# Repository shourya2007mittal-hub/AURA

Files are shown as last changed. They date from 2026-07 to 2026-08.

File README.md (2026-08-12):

# AURA


I made a custom Tailless twin motor RC Plane with custom Flight Controller (based on STM32). The Flight Controller  will have 2 IMU's and a barometer for precise data collection. The Plane design will include a tailless structure and the motions will be controlled by the flaps on the wings. I have also made custom ESc for the Plane as well.

## Features
- Base on  STM32F401CBUx 
- Has dual IMU (MPU_6050)(ICM-20948)
- Has a Barometer (BMP280)
- Uses 2 Light-Weight Servoes
- Uses Custom flight-controller
- Tailless twin motor Design
- Custom ESC for plane 

# ✈️ RC Plane Bill of Materials (BOM)

This repository contains the complete **Bill of Materials (BOM)** for the RC Plane project, including component quantities, unit prices, total costs, and supplier links.

## 📦 Bill of Materials

| Item | Quantity | Unit Price (USD) | Total Price (USD) | Source |
|---|:---:|---:|---:|---|
| PCB + PCBA (Flight Controller + ESC) | 1 | $253.46 | $253.46 | https://jlcpcb.com |
| PCB Shipping + coupons | 1 | $17.32 | $17.32 | https://jlcpcb.com |
| Brushless Motor | 2 | $15.20 | $30.40 | https://robu.in/product/r2207-2207-2450kv-ccw-fpv-brushless-motor/ |
| Receiver / Transmitter | 1 | $0 | $0 Funded by me |https://robocraze.com/products/fly-sky-fs-i6x-2-4ghz-6ch-afhds-2a-rc-transmitter-with-fs-ia10b-2-4ghz-10ch-receiver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 |
| 12V Battery | 1 | $5.78 | $5.78 | https://robocraze.com/products/11-1v-2200mah-li-ion-battery?_pos=18&_sid=25292ddd5&_ss=r |
| SG90 Servo | 2 | $0.96 | $1.92 | https://robocraze.com/products/sg90-micro-servo-motor?_pos=1&_sid=88e48e080&_ss=r |
| 3D Printed Plane | 1 | $41.86 | $41.86 |https://jlc3dp.com/ |

---

## 💰 Cost Summary

| Category | Amount (USD) |
|---|---:|
| Total Component Cost | **$352.74** |

---

## 📋 Components Included

- PCB + PCBA
- PCB Shipping
- Brushless Motors (×2)
- Electronic Speed Controllers (ESCs) (×2)
- Receiver / Transmitter
- 12V Battery
- SG90 Micro Servos (×2)
- 3D Printed Aircraft Frame

### Schematic Flight Controller


###  PCB Design Flight Controller




### Schematic ESC


###  PCB Design ESC




### 3D Design 






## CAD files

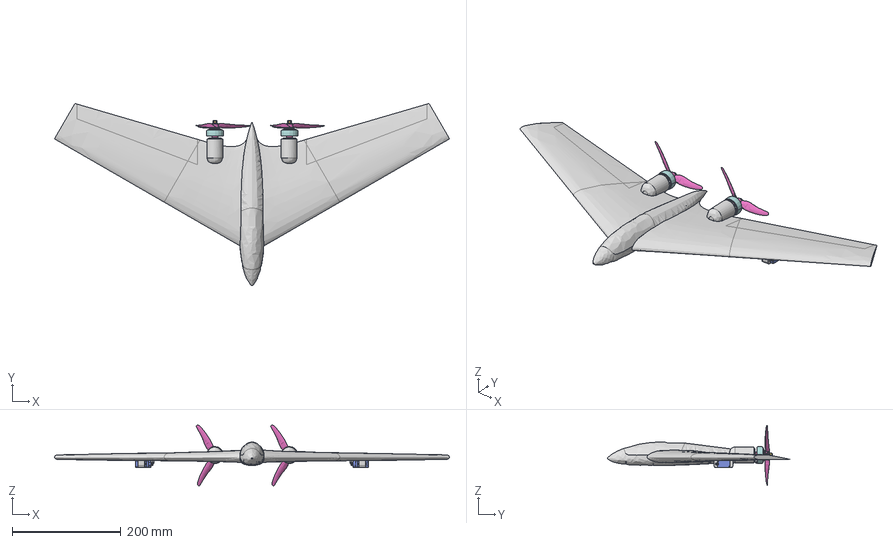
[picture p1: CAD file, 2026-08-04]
CAD/Aura.step
726.0 x 334.6 x 111.7 mm
D_SMA x 2
R_0603_1608Metric (1) x 62
C_0805_2012Metric x 10
PinHeader_1x01_P254mm_Vertical x 10
C_1206_3216Metric x 10
SOT-223 x 2
C_0603_1608Metric x 6
R_2512_6332Metric x 2
PinHeader_1x03_P254mm_Vertical x 2
PinHeader_1x04_P254mm_Vertical x 2
D_SOD_523 x 6
SOT-23-6 x 2
R_eA4A7_PCB x 2

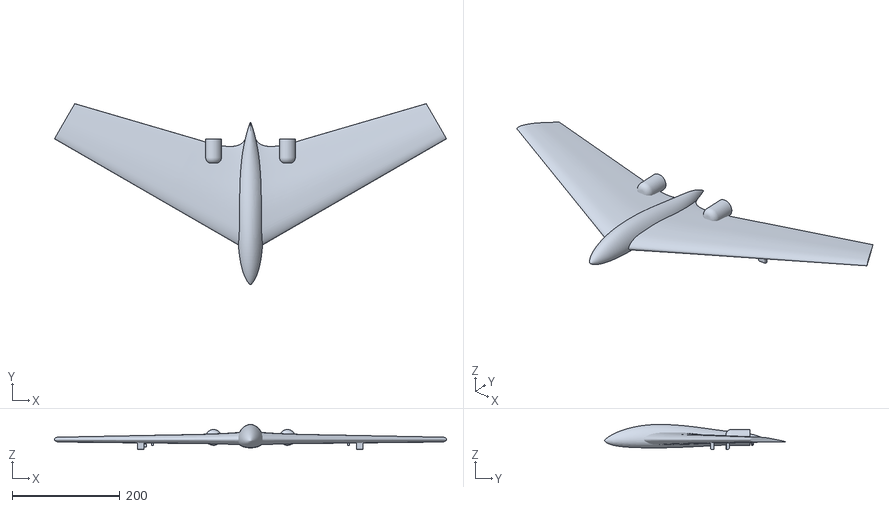
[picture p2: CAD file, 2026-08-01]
Production/CAD/AURA.stl
726.0 x 334.6 x 46.5

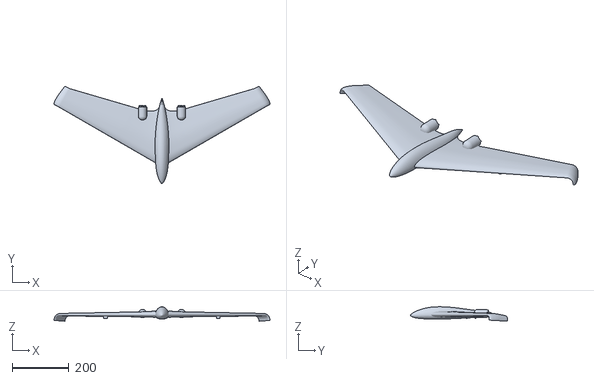
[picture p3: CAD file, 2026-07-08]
Production/CAD/AURA3D.stl
760.6 x 343.3 x 51.2

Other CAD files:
CAD/Aura.f3d

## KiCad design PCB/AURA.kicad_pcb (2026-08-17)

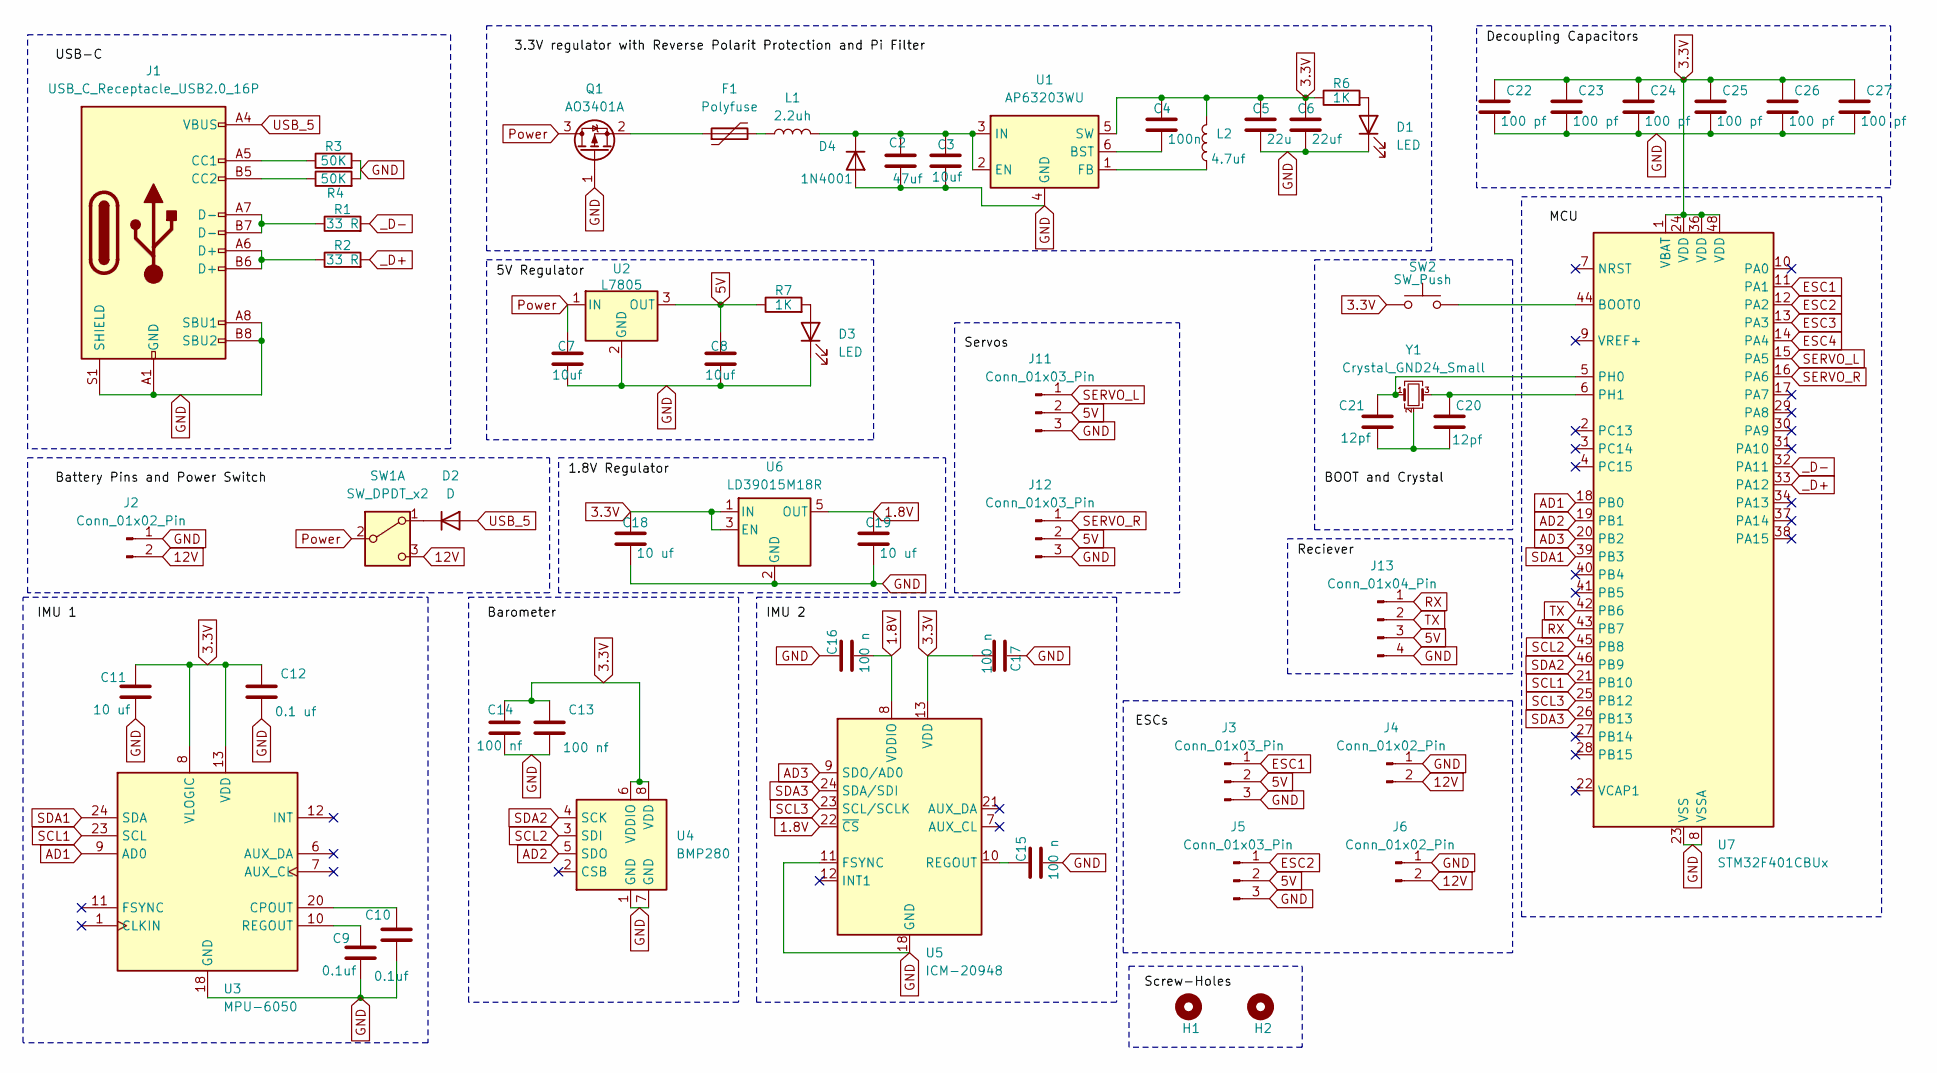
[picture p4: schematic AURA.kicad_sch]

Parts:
C2: 47uf; C_0201_0603Metric
C3, C7, C8: 10uf; C_0201_0603Metric
C4: 100n; C_0201_0603Metric
C5: 22u; C_0201_0603Metric
C6: 22uf; C_0201_0603Metric
C9, C10: 0.1uf; C_0201_0603Metric
C11, C18, C19: 10 uf; C_0201_0603Metric
C12: 0.1 uf; C_0201_0603Metric
C13, C14: 100 nf; C_0201_0603Metric
C15, C16, C17: 100 n; C_0201_0603Metric
C20, C21: 12pf; C_0201_0603Metric
C22, C23, C24, C25, C26, C27: 100 pf; C_0201_0603Metric
D1, D3: LED; LED_0201_0603Metric
D2: D; D_0201_0603Metric
D4: 1N4001; D_DO-41_SOD81_P5.08mm_Vertical_AnodeUp
F1: Polyfuse; C_0201_0603Metric
H1, H2: MountingHole; MountingHole_2.5mm_Pad
J1: USB_C_Receptacle_USB2.0_16P; USB_C_Receptacle_G-Switch_GT-USB-7010ASV
J2: Conn_01x02_Pin; AMASS_XT60-M_1x02_P7.20mm_Vertical
J3, J5, J11, J12: Conn_01x03_Pin; JST_EH_B3B-EH-A_1x03_P2.50mm_Vertical
J4, J6: Conn_01x02_Pin; AMASS_XT60-F_1x02_P7.20mm_Vertical
J13: Conn_01x04_Pin; JST_EH_B4B-EH-A_1x04_P2.50mm_Vertical
L1: 2.2uh; L_0603_1608Metric
L2: 4.7uf; L_0603_1608Metric
Q1: AO3401A; SOT-23
R1, R2: 33 R; R_0201_0603Metric_Pad0.64x0.40mm_HandSolder
R3, R4: 50K; R_0201_0603Metric_Pad0.64x0.40mm_HandSolder
R6, R7: 1K; R_0201_0603Metric_Pad0.64x0.40mm_HandSolder
SW1: SW_DPDT_x2; SW_PUSH_E-Switch_FS5700DP_DPDT
SW2: SW_Push; SW_Tactile_Straight_KSA0Axx1LFTR
U1: AP63203WU; TSOT-23-6
U2: L7805; TO-252-2
U3: MPU-6050; InvenSense_QFN-24_4x4mm_P0.5mm
U4: BMP280; Bosch_LGA-8_2x2.5mm_P0.65mm_ClockwisePinNumbering
U5: ICM-20948; InvenSense_QFN-24_3x3mm_P0.4mm
U6: LD39015M18R; SOT-23-5
U7: STM32F401CBUx; QFN-48-1EP_7x7mm_P0.5mm_EP5.6x5.6mm
Y1: Crystal_GND24_Small; Crystal_SMD_0603-4Pin_6.0x3.5mm

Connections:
1.8V: C16.2, C19.1, U5.8 (VDDIO), U5.22 (~CS), U6.5 (OUT)
3.3V: C4.1, C5.1, C6.1, C11.1, C12.1, C13.1, C14.1, C17.2, C18.1, C22.1, C23.1, C24.1, C25.1, C26.1, C27.1, L2.2, R6.1, SW2.1, U1.5 (SW), U3.8 (VLOGIC), U3.13 (VDD), U4.6 (VDDIO), U4.8 (VDD), U5.13 (VDD), U6.1 (IN), U6.3 (EN), U7.1 (VBAT), U7.24 (VDD), U7.36 (VDD), U7.48 (VDD)
5V: C8.1, J3.2, J5.2, J11.2, J12.2, J13.3, R7.1, U2.3 (OUT)
12V: J2.2, J4.2, J6.2, SW1.3 (C)
AD1: U3.9 (AD0), U7.18 (PB0)
AD2: U4.5 (SDO), U7.19 (PB1)
AD3: U5.9 (SDO/AD0), U7.20 (PB2)
ESC1: J3.1, U7.11 (PA1)
ESC2: J5.1, U7.12 (PA2)
ESC3: U7.13 (PA3)
ESC4: U7.14 (PA4)
GND: C2.2, C3.2, C5.2, C6.2, C7.2, C8.2, C9.2, C10.2, C11.2, C12.2, C13.2, C14.2, C15.2, C16.1, C17.1, C18.2, C19.2, C22.2, C23.2, C24.2, C25.2, C26.2, C27.2, D1.1 (K), D3.1 (K), D4.2 (A), J1.A1 (GND), J1.A8 (SBU1), J1.A12 (GND), J1.B1 (GND), J1.B8 (SBU2), J1.B12 (GND), J1.S1 (SHIELD), J2.1, J3.3, J4.1, J5.3, J6.1, J11.3, J12.3, J13.4, Q1.1 (G), R3.2, R4.2, U1.4 (GND), U2.2 (GND), U3.18 (GND), U4.1 (GND), U4.7 (GND), U5.11 (FSYNC), U5.18 (GND), U5.20 (GND), U6.2 (GND), U7.8 (VSSA), U7.23 (VSS), U7.35 (VSS), U7.47 (VSS), U7.49 (VSS)
unnamed: C20.2, C21.2, Y1.2 (G), Y1.4 (G)
unnamed: D1.2 (A), R6.2
unnamed: D2.1 (K), SW1.1 (A)
unnamed: D3.2 (A), R7.2
unnamed: C2.1, C3.1, D4.1 (K), L1.2, U1.2 (EN), U1.3 (IN)
unnamed: F1.2, L1.1
unnamed: J1.A5 (CC1), R3.1
unnamed: J1.B5 (CC2), R4.1
unnamed: J1.A6 (D+), J1.B6 (D+), R2.1
unnamed: J1.A7 (D-), J1.B7 (D-), R1.1
unnamed: F1.1, Q1.2 (S)
unnamed: C4.2, U1.6 (BST)
unnamed: L2.1, U1.1 (FB)
unnamed: C10.1, U3.20 (CPOUT)
unnamed: C9.1, U3.10 (REGOUT)
unnamed: C15.1, U5.10 (REGOUT)
unnamed: SW2.2, U7.44 (BOOT0)
unnamed: C21.1, U7.5 (PH0), Y1.1
unnamed: C20.1, U7.6 (PH1), Y1.3
Power: C7.1, Q1.3 (D), SW1.2 (B), U2.1 (IN)
RX: J13.1, U7.43 (PB7)
SCL1: U3.23 (SCL), U7.21 (PB10)
SCL2: U4.3 (SDI), U7.45 (PB8)
SCL3: U5.23 (SCL/SCLK), U7.25 (PB12)
SDA1: U3.24 (SDA), U7.39 (PB3)
SDA2: U4.4 (SCK), U7.46 (PB9)
SDA3: U5.24 (SDA/SDI), U7.26 (PB13)
SERVO_L: J11.1, U7.15 (PA5)
SERVO_R: J12.1, U7.16 (PA6)
TX: J13.2, U7.42 (PB6)
USB_5: D2.2 (A), J1.A4 (VBUS), J1.A9 (VBUS), J1.B4 (VBUS), J1.B9 (VBUS)
_D+: R2.2, U7.33 (PA12)
_D-: R1.2, U7.32 (PA11)

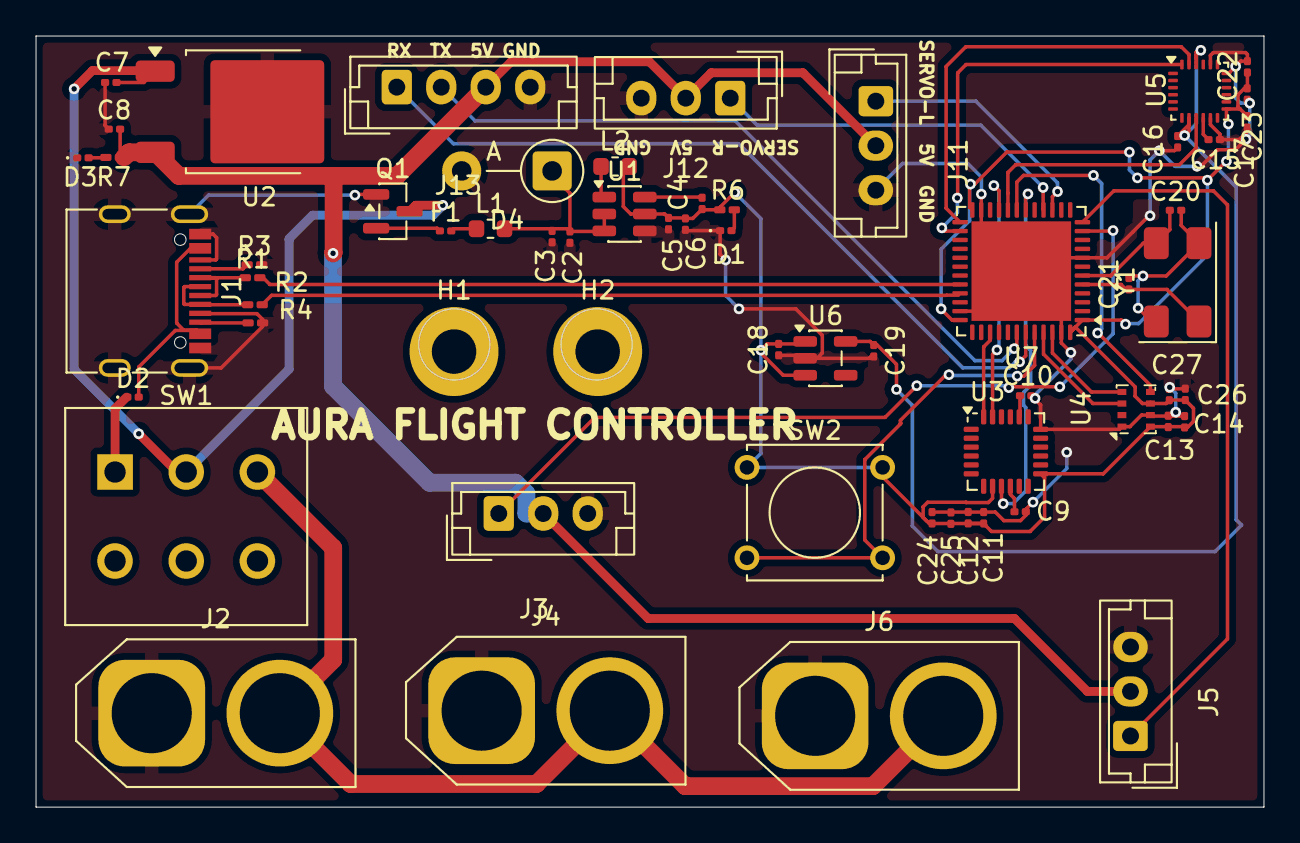
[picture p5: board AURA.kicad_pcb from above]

Board: 2 copper layers, 69.0 x 43.3 mm, 61 parts (0 on the bottom side), 43 nets.

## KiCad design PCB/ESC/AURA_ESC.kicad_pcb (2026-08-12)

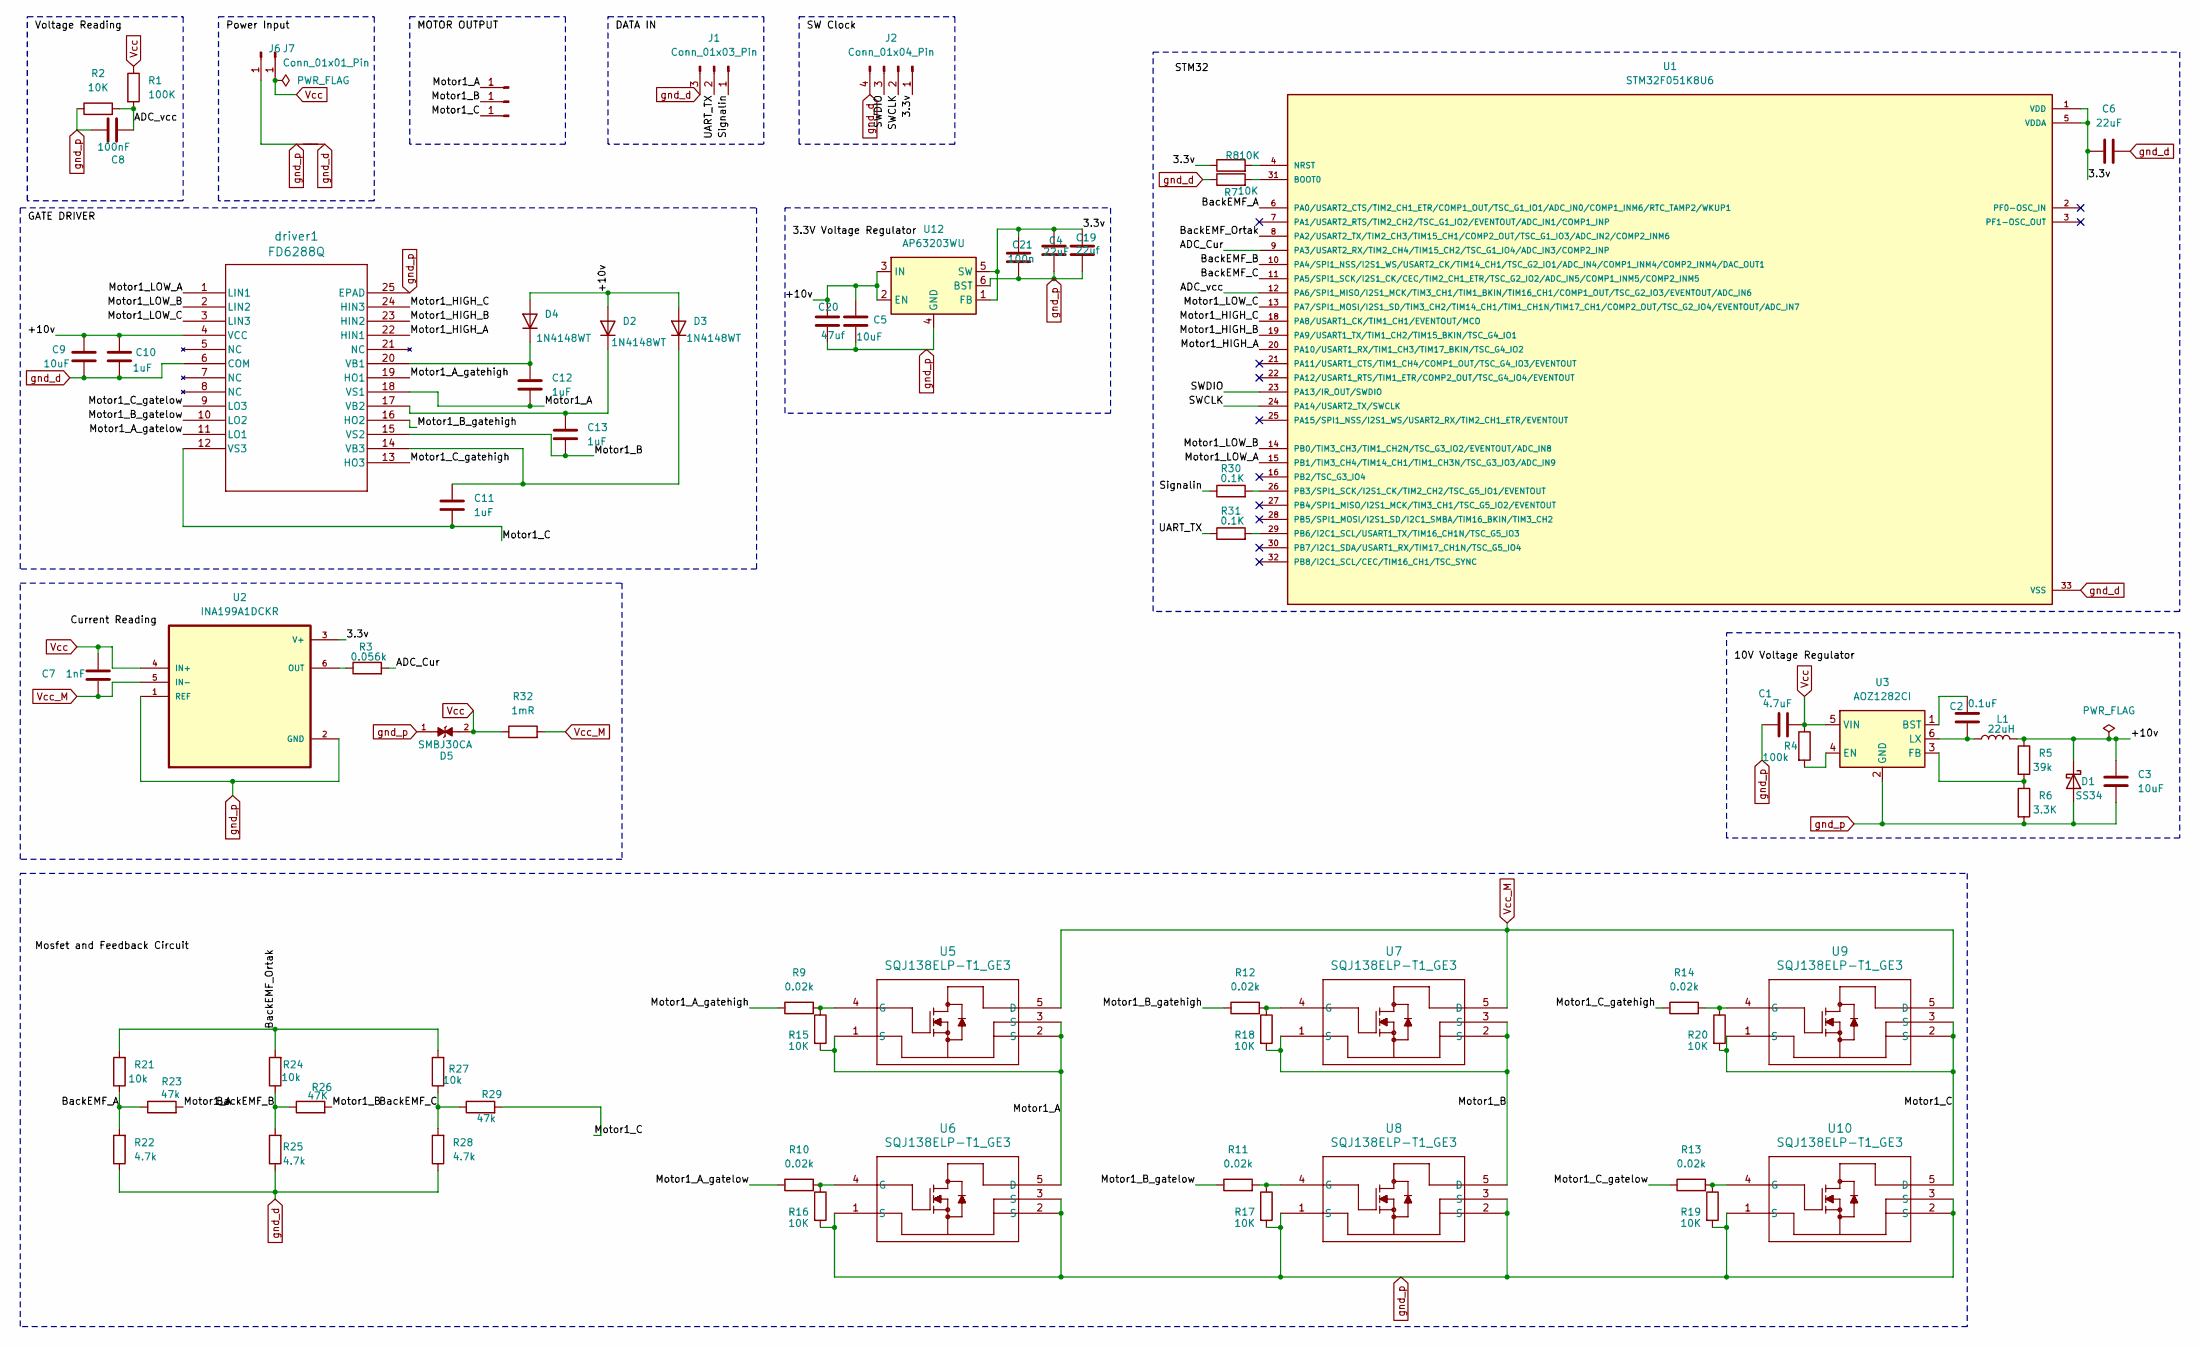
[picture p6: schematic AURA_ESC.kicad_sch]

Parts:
C1: 4.7uF; C_0805_2012Metric
C2: 0.1uF; C_0603_1608Metric
C3, C5, C9: 10uF; C_1206_3216Metric
C4, C6: 22uF; C_1206_3216Metric
C7: 1nF; C_0603_1608Metric
C8: 100nF; C_0603_1608Metric
C10, C11, C12, C13: 1uF; C_0805_2012Metric
C19: 22uf; C_0201_0603Metric
C20: 47uf; C_0201_0603Metric
C21: 100n; C_0201_0603Metric
D1: SS34; D_SMA
D2, D3, D4: 1N4148WT; D_SOD-523
D5: SMBJ30CA; DIOM4336X265N; PARTREV I2102
J1: Conn_01x03_Pin; PinHeader_1x03_P2.54mm_Vertical
J2: Conn_01x04_Pin; PinHeader_1x04_P2.54mm_Vertical
J3, J4, J5, J6, J7: Conn_01x01_Pin; PinHeader_1x01_P2.54mm_Vertical
L1: 22uH; L_6.3x6.3_H3
NT1: NetTie_2; NetTie-2_SMD_Pad0.5mm
R1: 100K; R_0603_1608Metric
R2, R7, R8, R15, R16, R17, R18, R19, R20: 10K; R_0603_1608Metric
R3: 0.056k; R_0603_1608Metric
R4: 100k; R_0603_1608Metric
R5: 39k; R_0603_1608Metric
R6: 3.3K; R_0603_1608Metric
R9, R10, R11, R12, R13, R14: 0.02k; R_0603_1608Metric
R21, R24, R27: 10k; R_0603_1608Metric
R22, R25, R28: 4.7k; R_0603_1608Metric
R23, R29: 47k; R_0603_1608Metric
R26: 47K; R_0603_1608Metric
R30, R31: 0.1K; R_0603_1608Metric
R32: 1mR; R_2512_6332Metric
U1: STM32F051K8U6; QFN50P500X500X60-33N; PARTREV 7
U2: INA199A1DCKR; SOT65P210X110-6N
U3: AOZ1282CI; SOT-23-6
U5, U6, U7, U8, U9, U10: SQJ138ELP-T1_GE3; PowerPAK_SO-8L_3_VIS
U12: AP63203WU; TSOT-23-6
driver1: FD6288Q; QFN24_FOR-M

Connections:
/+10v: C3.1, C5.1, C9.1, C10.1, C20.1, D1.1 (K), D2.2 (A), D3.2 (A), D4.2 (A), L1.2, R5.1, U12.2 (EN), U12.3 (IN), driver1.4 (VCC)
/ADC_Cur: R3.2, U1.9 (PA3/USART2_RX/TIM2_CH4/TIM15_CH2/TSC_G1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)
/ADC_vcc: C8.2, R1.2, R2.2, U1.12 (PA6/SPI1_MISO/I2S1_MCK/TIM3_CH1/TIM1_BK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)
/BackEMF_A: R21.1, R22.2, R23.1, U1.6 (PA0/USART2_CTS/TIM2_CH1_ETR/COMP1_OUT/T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)
/BackEMF_B: R24.1, R25.2, R26.1, U1.10 (PA4/SPI1_NSS/I2S1_WS/USART2_CK/TIM14_CH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)
/BackEMF_C: R27.1, R28.2, R29.1, U1.11 (PA5/SPI1_SCK/I2S1_CK/CEC/TIM2_CH1_ETR/T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)
/BackEMF_Ortak: R21.2, R24.2, R27.2, U1.8 (PA2/USART2_TX/TIM2_CH3/TIM15_CH1/COMP2_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)
/Motor1_A: C12.2, J3.1 (Pin_1_1), R15.2, R23.2, U5.1 (S), U5.2 (S), U5.3 (S), U6.5 (D), driver1.18 (VS1)
/Motor1_A_gatehigh: R9.1, driver1.19 (HO1)
/Motor1_A_gatelow: R10.1, driver1.11 (LO1)
/Motor1_B: C13.2, J4.1 (Pin_1_1), R18.2, R26.2, U7.1 (S), U7.2 (S), U7.3 (S), U8.5 (D), driver1.15 (VS2)
/Motor1_B_gatehigh: R12.1, driver1.16 (HO2)
/Motor1_B_gatelow: R11.1, driver1.10 (LO2)
/Motor1_C: C11.2, J5.1 (Pin_1_1), R20.2, R29.2, U9.1 (S), U9.2 (S), U9.3 (S), U10.5 (D), driver1.12 (VS3)
/Motor1_C_gatehigh: R14.1, driver1.13 (HO3)
/Motor1_C_gatelow: R13.1, driver1.9 (LO3)
/Motor1_HIGH_A: U1.20 (PA10/USART1_RX/TIM1_CH3/TIM17_BKIN/TSC_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), driver1.22 (HIN1)
/Motor1_HIGH_B: U1.19 (PA9/USART1_TX/TIM1_CH2/TIM15_BKIN/TSC_G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), driver1.23 (HIN2)
/Motor1_HIGH_C: U1.18 (PA8/USART1_CK/TIM1_CH1/EVENTOUT/MCO), driver1.24 (HIN3)
/Motor1_LOW_A: U1.15 (PB1/TIM3_CH4/TIM14_CH1/TIM1_CH3N/TSC_G3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), driver1.1 (LIN1)
/Motor1_LOW_B: U1.14 (PB0/TIM3_CH3/TIM1_CH2N/TSC_G3_IO2/EVENT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), driver1.2 (LIN2)
/Motor1_LOW_C: U1.13 (PA7/SPI1_MOSI/I2S1_SD/TIM3_CH2/TIM14_CH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), driver1.3 (LIN3)
/SWCLK: J2.2, U1.24 (PA14/USART2_TX/SWCLK)
/SWDIO: J2.3, U1.23 (PA13/IR_OUT/SWDIO)
/Signalin: J1.1, R30.1
/UART_TX: J1.2, R31.1
unnamed: C13.1, D2.1 (K), driver1.17 (VB2)
unnamed: C11.1, D3.1 (K), driver1.14 (VB3)
unnamed: C12.1, D4.1 (K), driver1.20 (VB1)
unnamed: R7.2, U1.31 (BOOT0)
unnamed: R8.2, U1.4 (NRST)
unnamed: R30.2, U1.26 (PB3/SPI1_SCK/I2S1_CK/TIM2_CH2/TSC_G5_IO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)
unnamed: R31.2, U1.29 (PB6/I2C1_SCL/USART1_TX/TIM16_CH1N/TSC_G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)
unnamed: R3.1, U2.6 (OUT)
unnamed: C2.1, U3.1 (BST)
unnamed: R4.2, U3.4 (EN)
unnamed: R5.2, R6.1, U3.3 (FB)
unnamed: C2.2, L1.1, U3.6 (LX)
unnamed: R9.2, R15.1, U5.4 (G)
unnamed: R10.2, R16.1, U6.4 (G)
unnamed: R12.2, R18.1, U7.4 (G)
unnamed: R11.2, R17.1, U8.4 (G)
unnamed: R14.2, R20.1, U9.4 (G)
unnamed: R13.2, R19.1, U10.4 (G)
VDD: C4.1, C6.2, C19.1, C21.1, J2.1, R8.1, U1.1 (VDD), U1.5 (VDDA), U1.17 (VDD), U2.3 (V+), U12.1 (FB), U12.5 (SW)
Vcc: C1.1, C7.2, D5.2, J7.1 (Pin_1_1), R1.1, R4.1, R32.1, U2.4 (IN+), U3.5 (VIN)
Vcc_M: C7.1, R32.2, U2.5 (IN-), U5.5 (D), U7.5 (D), U9.5 (D)
gnd_d: C6.1, C9.2, C10.2, J1.3, J2.4, NT1.2, R7.1, R22.1, R25.1, R28.1, U1.33 (VSS), driver1.6 (COM)
gnd_p: C1.2, C3.2, C4.2, C5.2, C8.1, C19.2, C20.2, C21.2, D1.2 (A), D5.1, J6.1 (Pin_1_1), NT1.1, R2.1, R6.2, R16.2, R17.2, R19.2, U2.1 (REF), U2.2 (GND), U3.2 (GND), U6.1 (S), U6.2 (S), U6.3 (S), U8.1 (S), U8.2 (S), U8.3 (S), U10.1 (S), U10.2 (S), U10.3 (S), U12.4 (GND), U12.6 (BST), driver1.25 (EPAD)

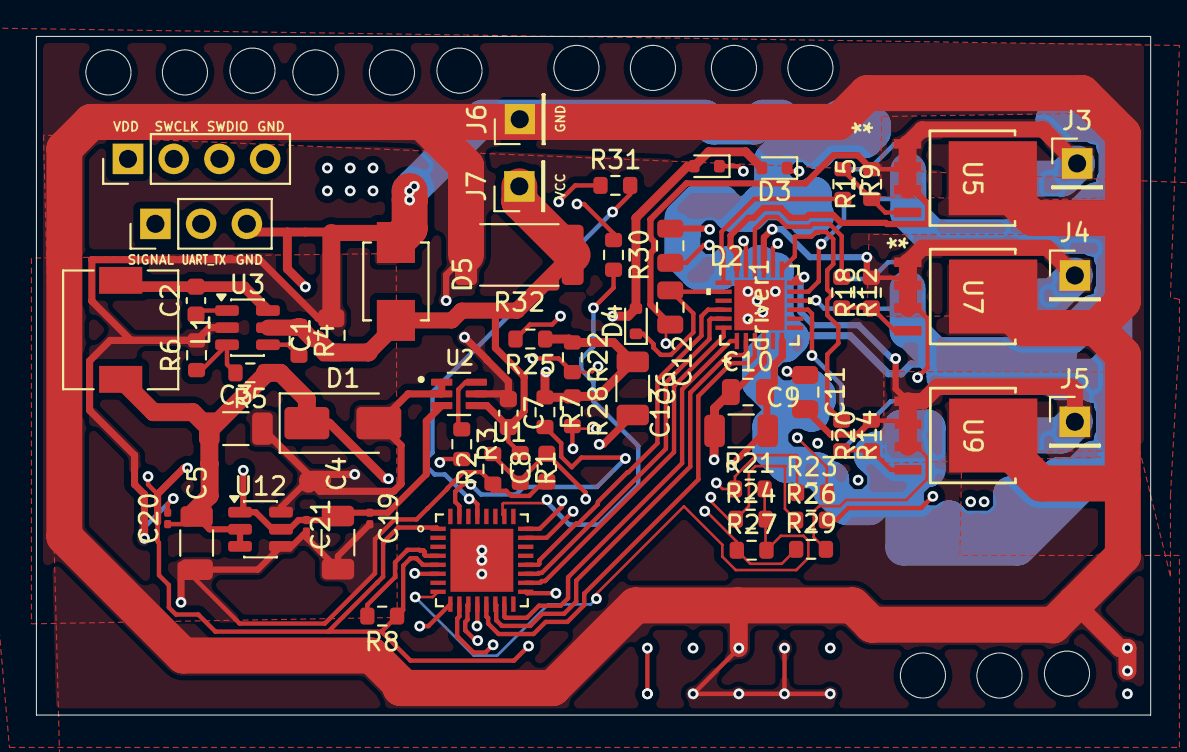
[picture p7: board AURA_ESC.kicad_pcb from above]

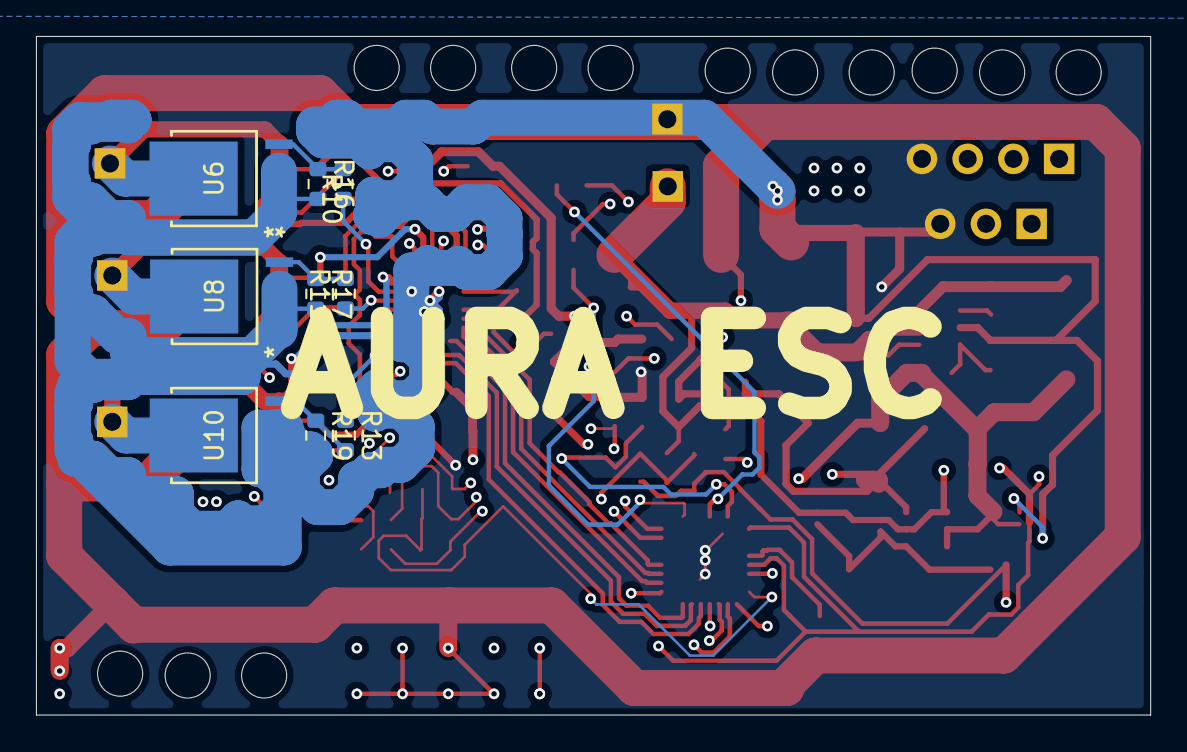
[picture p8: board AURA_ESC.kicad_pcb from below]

Board: 4 copper layers, 61.9 x 37.7 mm, 73 parts (9 on the bottom side), 49 nets.

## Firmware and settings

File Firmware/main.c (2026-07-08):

/*
 * ============================================================================
 * CUSTOM TAILLESS TWIN-MOTOR FLIGHT CONTROLLER FIRMWARE
 * Target MCU: STM32F401CBUx
 * ============================================================================
 */

#include "main.h"
#include <math.h>

// --- DEFINITIONS & CONSTANTS ---
#define MPU6050_ADDR    (0x68 << 1)
#define BMP280_ADDR     (0x76 << 1)
#define SBUS_FRAME_SIZE 25

// --- PERIPHERAL HANDLES ---
I2C_HandleTypeDef hi2c1;   // IMU 1 (MPU6050) via PB6/PB7
I2C_HandleTypeDef hi2c2;   // Barometer (BMP280) via PB10/PB3
TIM_HandleTypeDef htim1;   // ESCs (PA8, PA9)
TIM_HandleTypeDef htim2;   // Servos (PA0, PA1)
UART_HandleTypeDef huart1; // SBUS Receiver Input (PA10)

// --- FLIGHT CONTROL VARIABLES ---
float roll_input = 0.0f, pitch_input = 0.0f, throttle_input = 1000.0f;
float current_roll = 0.0f, current_pitch = 0.0f;
float gyro_bias_x = 0.0f, gyro_bias_y = 0.0f;

// PID Tuning Constants (Adjust these during test flights)
float Kp_roll = 1.2f,  Ki_roll = 0.05f,  Kd_roll = 0.1f;
float Kp_pitch = 1.5f, Ki_pitch = 0.05f, Kd_pitch = 0.1f;

// PID Memory Registers
float error_roll, integral_roll, derivative_roll, last_error_roll, out_roll;
float error_pitch, integral_pitch, derivative_pitch, last_error_pitch, out_pitch;

// SBUS Protocol Variables
uint8_t sbus_buffer[SBUS_FRAME_SIZE];
uint16_t sbus_channels[4];
uint8_t sbus_index = 0;
uint8_t is_armed = 0;
uint8_t rx_byte;

// Barometer Calibration Factors
uint16_t dig_T1; int16_t dig_T2, dig_T3; uint16_t dig_P1;
int16_t dig_P2, dig_P3, dig_P4, dig_P5, dig_P6, dig_P7, dig_P8, dig_P9;

// --- FUNCTION PROTOTYPES ---
void SystemClock_Config(void);
static void MX_GPIO_Init(void);
static void MX_I2C1_Init(void);
static void MX_I2C2_Init(void);
static void MX_TIM1_Init(void);
static void MX_TIM2_Init(void);
static void MX_USART1_UART_Init(void);

void IMU_Calibrate(void);
void IMU_Read(float *r, float *p);
void BMP280_Init(void);
float BMP280_GetAltitude(void);
void Mix_Elevons(float throttle, float roll, float pitch);

// --- MAIN PROGRAM EXECUTION ---
int main(void) {
    // Reset of all peripherals, Initializes the Flash interface and the Systick.
    HAL_Init();

    // Configure the system clock to 84 MHz using the 25MHz external crystal
    SystemClock_Config();

    // Initialize all configured peripherals
    MX_GPIO_Init();
    MX_I2C1_Init();
    MX_I2C2_Init();
    MX_TIM1_Init();
    MX_TIM2_Init();
    MX_USART1_UART_Init();

    // Device Sensors Boot & Calibration Sequence
    BMP280_Init();
    IMU_Calibrate();
    
    // Start Non-blocking UART Reception for RC Signal
    HAL_UART_Receive_IT(&huart1, &rx_byte, 1);

    // Start PWM Hardware Timers
    HAL_TIM_PWM_Start(&htim1, TIM_CHANNEL_1); // Left ESC
    HAL_TIM_PWM_Start(&htim1, TIM_CHANNEL_2); // Right ESC
    HAL_TIM_PWM_Start(&htim2, TIM_CHANNEL_1); // Left Servo
    HAL_TIM_PWM_Start(&htim2, TIM_CHANNEL_2); // Right Servo

    uint32_t loop_timer = HAL_GetTick();

    while (1) {
        // Main Flight Controller Loop (Executes strictly at 200Hz -> every 5ms)
        if ((HAL_GetTick() - loop_timer) >= 5) {
            loop_timer = HAL_GetTick();

            // 1. Refresh Flight Performance Matrix Data
            IMU_Read(&current_roll, &current_pitch);
            float current_altitude = BMP280_GetAltitude();

            // 2. Structural Safety Timeout Arm Interlock
            if (!is_armed) {
                __HAL_TIM_SET_COMPARE(&htim1, TIM_CHANNEL_1, 1000); // Force Motors Off
                __HAL_TIM_SET_COMPARE(&htim1, TIM_CHANNEL_2, 1000);
                continue; // Skip PID execution if safety switch is down
            }

            // 3. Roll Axis PID Controller
            error_roll = roll_input - current_roll;
            integral_roll += error_roll * 0.005f;
            derivative_roll = (error_roll - last_error_roll) / 0.005f;
            out_roll = (Kp_roll * error_roll) + (Ki_roll * integral_roll) + (Kd_roll * derivative_roll);
            last_error_roll = error_roll;

            // 4. Pitch Axis PID Controller
            error_pitch = pitch_input - current_pitch;
            integral_pitch += error_pitch * 0.005f;
            derivative_pitch = (error_pitch - last_error_pitch) / 0.005f;
            out_pitch = (Kp_pitch * error_pitch) + (Ki_pitch * integral_pitch) + (Kd_pitch * derivative_pitch);
            last_error_pitch = error_pitch;

            // 5. Send Mixed Commands to Control Surfaces and Power Units
            Mix_Elevons(throttle_input, out_roll, out_pitch);
        }
    }
}

// --- MIXING & CONTROL SURFACE LOGIC ---
void Mix_Elevons(float throttle, float roll, float pitch) {
    // Elevon Aerodynamic Mixer Logic for Tailless Aircraft
    float s_left  = 1500 + pitch + roll;
    float s_right = 1500 - pitch + roll;

    // Hard Clip Servo Output Constraints (1000us to 2000us)
    s_left  = (s_left > 2000) ? 2000 : ((s_left < 1000) ? 1000 : s_left);
    s_right = (s_right > 2000) ? 2000 : ((s_right < 1000) ? 1000 : s_right);

    __HAL_TIM_SET_COMPARE(&htim2, TIM_CHANNEL_1, (uint32_t)s_left);
    __HAL_TIM_SET_COMPARE(&htim2, TIM_CHANNEL_2, (uint32_t)s_right);

    // Twin Engine Differential Thrust Mixing to assist Yaw Control
    float esc_l = throttle + (roll * 0.15f);
    float esc_r = throttle - (roll * 0.15f);

    // Protect against motor overflow parameters
    esc_l = (esc_l > 2000) ? 2000 : ((esc_l < 1000) ? 1000 : esc_l);
    esc_r = (esc_r > 2000) ? 2000 : ((esc_r < 1000) ? 1000 : esc_r);

    __HAL_TIM_SET_COMPARE(&htim1, TIM_CHANNEL_1, (uint32_t)esc_l);
    __HAL_TIM_SET_COMPARE(&htim1, TIM_CHANNEL_2, (uint32_t)esc_r);
}

// --- IMU TRANSLATION & CALIBRATION DRIVERS ---
void IMU_Calibrate(void) {
    uint8_t data[6];
    int32_t gx = 0, gy = 0;
    
    // Hold completely level and stable during initialization
    for (int i = 0; i < 400; i++) {
        HAL_I2C_Mem_Read(&hi2c1, MPU6050_ADDR, 0x43, I2C_MEMADD_SIZE_8BIT, data, 6, 10);
        gx += (int16_t)((data[0] << 8) | data[1]);
        gy += (int16_t)((data[2] << 8) | data[3]);
        HAL_Delay(2);
    }
    gyro_bias_x = (float)gx / 400.0f / 65.5f;
    gyro_bias_y = (float)gy / 400.0f / 65.5f;
}

void IMU_Read(float *r, float *p) {
    uint8_t data[6];
    HAL_I2C_Mem_Read(&hi2c1, MPU6050_ADDR, 0x3B, I2C_MEMADD_SIZE_8BIT, data, 6, 10);
    int16_t ax = (data[0] << 8) | data[1];
    int16_t ay = (data[2] << 8) | data[3];
    int16_t az = (data[4] << 8) | data[5];

    // Compute Pitch/Roll orientation vectors from Accelerometer forces
    float acc_roll  = atan2f((float)ay, (float)az) * 57.2957f;
    float acc_pitch = atan2f(-(float)ax, sqrtf((float)ay*(float)ay + (float)az*(float)az)) * 57.2957f;

    // Complimentary Noise Filtering step
    *r = 0.98f * (*r) + 0.02f * acc_roll;
    *p = 0.98f * (*p) + 0.02f * acc_pitch;
}

// --- BAROMETER SENSOR INTERFACE ---
void BMP280_Init(void) {
    uint8_t calib[24], config[2] = {0xF4, 0x57};
    HAL_I2C_Mem_Read(&hi2c2, BMP280_ADDR, 0x88, I2C_MEMADD_SIZE_8BIT, calib, 24, 100);
    
    dig_T1 = (calib[1] << 8) | calib[0]; dig_T2 = (calib[3] << 8) | calib[2];
    dig_P1 = (calib[7] << 8) | calib[6]; dig_P2 = (calib[9] << 8) | calib[8];
    
    HAL_I2C_Master_Transmit(&hi2c2, BMP280_ADDR, config, 2, 100);
}

float BMP280_GetAltitude(void) {
    uint8_t data[6];
    HAL_I2C_Mem_Read(&hi2c2, BMP280_ADDR, 0xF7, I2C_MEMADD_SIZE_8BIT, data, 3, 100);
    int32_t adc_P = (data[0] << 12) | (data[1] << 4) | (data[2] >> 4);
    
    // Returns estimated altitude value in relative meters
    return 44330.0f * (1.0f - powf(((float)adc_P / 256.0f) / 101325.0f, 0.1903f));
}

// --- INTERRUPT BASED SBUS DATA RECEIVER ---
void HAL_UART_RxCpltCallback(UART_HandleTypeDef *huart) {
    if (huart->Instance == USART1) {
        uint8_t byte = rx_byte;
        
        if (sbus_index == 0 && byte != 0x0F) return; // Verify frame start bit
        
        sbus_buffer[sbus_index++] = byte;
        
        if (sbus_index == SBUS_FRAME_SIZE) {
            sbus_index = 0;
            if (sbus_buffer[24] == 0x00) { // Verify validity of end bit sequence
                sbus_channels[0] = ((sbus_buffer[1] | sbus_buffer[2] << 8) & 0x07FF);
                sbus_channels[1] = ((sbus_buffer[2] >> 3 | sbus_buffer[3] << 5) & 0x07FF);
                sbus_channels[2] = ((sbus_buffer[3] >> 6 | sbus_buffer[4] << 2) & 0x07FF);
                
                // Normalization mapping into standard PWM scale inputs
                roll_input     = (1000 + ((sbus_channels[0] - 172) * 1000 / 1639)) - 1500;
                pitch_input    = (1000 + ((sbus_channels[1] - 172) * 1000 / 1639)) - 1500;
                throttle_input = 1000 + ((sbus_channels[2] - 172) * 1000 / 1639);
                
                // Read specific bit flags to check the configuration state of safety switch
                is_armed = (sbus_buffer[23] & 0x01); 
            }
        }
        HAL_UART_Receive_IT(&huart1, &rx_byte, 1); // Re-arm the interrupt listener
    }
}

// --- HARDWARE SYSTEM CLOCK CONFIGURATION (84 MHz via HSE) ---
void SystemClock_Config(void) {
    RCC_OscInitTypeDef RCC_OscInitStruct = {0};
    RCC_ClkInitTypeDef RCC_ClkInitStruct = {0};

    __HAL_RCC_PWR_CLK_ENABLE();
    __HAL_PWR_VOLTAGESCALING_CONFIG(PWR_REGULATOR_VOLTAGE_SCALE_2);

    RCC_OscInitStruct.OscillatorType = RCC_OSCILLATORTYPE_HSE;
    RCC_OscInitStruct.HSEState = RCC_HSE_ON;
    RCC_OscInitStruct.PLL.PLLState = RCC_PLL_ON;
    RCC_OscInitStruct.PLL.PLLSource = RCC_PLLSOURCE_HSE;
    RCC_OscInitStruct.PLL.PLLM = 25;
    RCC_OscInitStruct.PLL.PLLN = 336;
    RCC_OscInitStruct.PLL.PLLP = RCC_PLLP_DIV4;
    RCC_OscInitStruct.PLL.PLLQ = 7;
    HAL_RCC_OscConfig(&RCC_OscInitStruct);

    RCC_ClkInitStruct.ClockType = RCC_CLOCKTYPE_HCLK|RCC_CLOCKTYPE_SYSCLK|RCC_CLOCKTYPE_PCLK1|RCC_CLOCKTYPE_PCLK2;
    RCC_ClkInitStruct.SYSCLKSource = RCC_SYSCLKSOURCE_PLLCLK;
    RCC_ClkInitStruct.AHBCLKDivider = RCC_SYSCLK_DIV1;
    RCC_ClkInitStruct.APB1CLKDivider = RCC_DIV2;
    RCC_ClkInitStruct.APB2CLKDivider = RCC_DIV1;
    HAL_RCC_ClockConfig(&RCC_ClkInitStruct, FLASH_LATENCY_2);
}

// --- BASIC PERIPHERAL LOW LEVEL INITIALIZERS ---
static void MX_I2C1_Init(void) {
    hi2c1.Instance = I2C1;
    hi2c1.Init.ClockSpeed = 100000;
    hi2c1.Init.DutyCycle = I2C_DUTYCYCLE_2;
    hi2c1.Init.OwnAddress1 = 0;
    hi2c1.Init.AddressingMode = I2C_ADDRESSINGMODE_7BIT;
    HAL_I2C_Init(&hi2c1);
}

static void MX_I2C2_Init(void) {
    hi2c2.Instance = I2C2;
    hi2c2.Init.ClockSpeed = 100000;
    hi2c2.Init.DutyCycle = I2C_DUTYCYCLE_2;
    HAL_I2C_Init(&hi2c2);
}

static void MX_TIM1_Init(void) {
    TIM_OC_InitTypeDef sConfigOC = {0};
    htim1.Instance = TIM1;
    htim1.Init.Prescaler = 84-1; // Clock tick resolution becomes 1 microsecond
    htim1.Init.Period = 20000-1; // 20ms Frame period -> 50Hz PWM Output frequency
    HAL_TIM_PWM_Init(&htim1);
    sConfigOC.OCMode = TIM_OCMODE_PWM1;
    sConfigOC.Pulse = 1000; // Initialize at safe idle pulse threshold
    HAL_TIM_PWM_ConfigChannel(&htim1, &sConfigOC, TIM_CHANNEL_1);
    HAL_TIM_PWM_ConfigChannel(&htim1, &sConfigOC, TIM_CHANNEL_2);
}

static void MX_TIM2_Init(void) {
    TIM_OC_InitTypeDef sConfigOC = {0};
    htim2.Instance = TIM2;
    htim2.Init.Prescaler = 84-1;
    htim2.Init.Period = 20000-1;
    HAL_TIM_PWM_Init(&htim2);
    sConfigOC.OCMode = TIM_OCMODE_PWM1;
    sConfigOC.Pulse = 1500; // Stabilize servos at exact midpoint baseline
    HAL_TIM_PWM_ConfigChannel(&htim2, &sConfigOC, TIM_CHANNEL_1);
    HAL_TIM_PWM_ConfigChannel(&htim2, &sConfigOC, TIM_CHANNEL_2);
}

static void MX_USART1_UART_Init(void) {
    huart1.Instance = USART1;
    huart1.Init.BaudRate = 100000; // Exact structural transmission frequency of SBUS
    huart1.Init.WordLength = UART_WORDLENGTH_9B;
    huart1.Init.StopBits = UART_STOPBITS_2;
    huart1.Init.Parity = UART_PARITY_EVEN;
    huart1.Init.Mode = UART_MODE_TX_RX;
    HAL_UART_Init(&huart1);
}

static void MX_GPIO_Init(void) {
    __HAL_RCC_GPIOH_CLK_ENABLE();
    __HAL_RCC_GPIOA_CLK_ENABLE();
    __HAL_RCC_GPIOB_CLK_ENABLE();
}
